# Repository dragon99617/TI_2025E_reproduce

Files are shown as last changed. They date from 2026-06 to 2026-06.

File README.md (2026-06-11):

# TI 2025E Reproduce

本项目用于复刻 2025 年全国大学生电子设计竞赛 E 题“简易自行瞄准装置”相关方案

## 项目目标

- 完成小车沿黑色方形轨迹自动循迹
- 支持设置行驶圈数 N
- 实现静态自动瞄准靶心
- 实现行驶中连续瞄准
- 支持后续扩展行驶中画圆等发挥功能
- 保持底盘控制链路由 TI MSPM0 系列 MCU 完成，便于满足题目约束

## 系统架构

```text
灰度传感器 / 编码器
        |
        v
LP-MSPM0G3507  --->  H 桥驱动  --->  底盘电机 x2
        |
      UART
        |
        v
达妙 H723  <---  maxicam 视觉模块
        |
       CAN
        |
        v
DM4310-2EC x2  --->  二维云台  --->  激光模块
```

## 硬件组成

| 模块 | 推荐器件 | 作用 |
| --- | --- | --- |
| 底盘主控 | LP-MSPM0G3507 | 循迹、编码器、底盘电机闭环 |
| 瞄准主控 | 达妙 H723 | 云台控制、视觉解析、激光控制 |
| 视觉模块 | maxicam | 靶面和激光点识别 |
| 云台电机 | 达妙 DM4310-2EC x2 | yaw/pitch 二自由度云台 |
| 底盘电机 | MG513X  x2 | 差速运动 |
| 电机驱动 | 双路 H 桥驱动 | 接收 MSPM0 的 PWM/DIR 控制 |
| 循迹传感器 | 7/8 路灰度传感器 | 黑线检测 |
| 电源 | 6S 锂电  | 分路供电 |

## 免责声明

本项目仅用于电子设计竞赛学习、资料整理和方案复刻。实际搭建和调试时，请注意锂电池、激光模块、电机和高电流供电相关安全，确保接线、固定和防护措施可靠。

请根据自身条件和比赛规则合理使用本项目内容。

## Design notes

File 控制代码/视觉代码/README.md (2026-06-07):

# Maxicam Vision for MaixCAM

This folder is a standalone MaixVision project. Open this folder or `main.py`
in MaixVision, upload it to MaixCAM, and run `main.py`.

## Defaults

- UART: `/dev/ttyS0`, `115200`
- UART pins: `A16` TX, `A17` RX
- Laser pin: `A18` as `GPIOA18`, active high
- Button pin: `A19` as `GPIOA19`, active low
- Camera resolution: tries `1920x1080`, then `1280x720`, `640x360`, `640x480`
- Camera rotation: disabled
- Algorithm: original traditional OpenCV rectangle/circle tracking

All hardware choices are in `config.py`.

## Button

- Short press: select next task
- Long press while idle: run selected task
- Long press while running: stop current task

## UART task commands

The same UART is reserved for task control input. Send ASCII text ending with
`\n` or `\r`.

- `1`: run task 1
- `2`: run task 2
- `3l`: run task 3 left
- `3r`: run task 3 right
- `4`: run task 4
- `5`: run task 5
- `6`: run task 6

Tracking output keeps the original lower-board protocol:

- angle: `dx,dy,0,0\n`
- speed search: `333,333,vx,vy\n`
- off: `666,666,0,0\n`

## Calibration

The original laser base point was `(285, 192)` at `640x360`. This project
scales it automatically for the active camera resolution. After mounting the
camera and laser, update `BASE_POINT_REF` in `config.py` if the hit point is
offset.

If MaixVision preview or OpenCV becomes too slow at `1920x1080`, move
`1280x720` to the first item in `CAMERA_RESOLUTIONS`.

## Wiring notes

MaixCAM IO is 3.3 V. Use a transistor, optocoupler, relay, or level circuit
for the laser driver and any 5 V lower board signal.

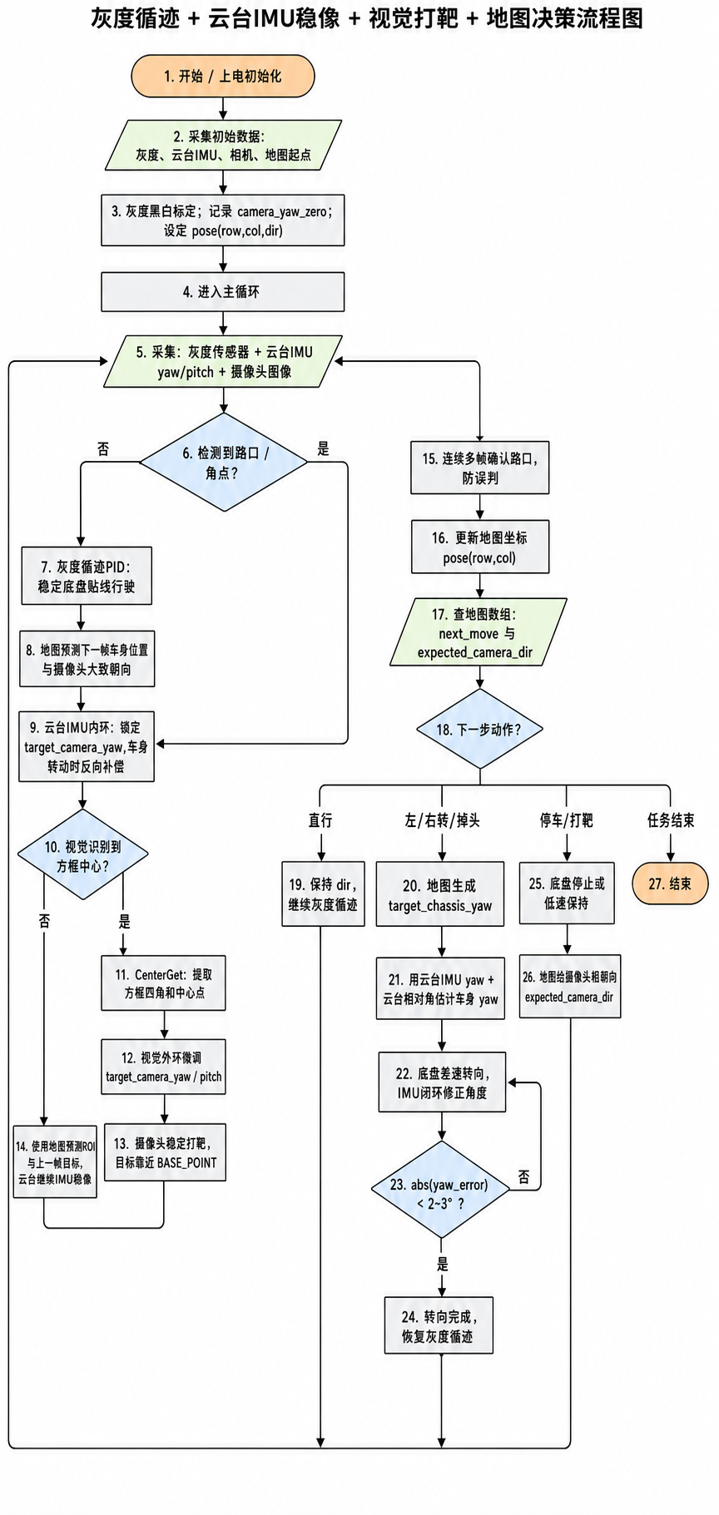
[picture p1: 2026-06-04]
控制代码/流程图.png

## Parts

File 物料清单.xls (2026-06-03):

元器件 | 预估单价 (￥)(淘宝) | 数量
达妙 4310-2EC V1.2 | 599 | 2
格氏 (Gens ace) 1300mAh 6S 75C (XT60) | 151.3 | 1
SkyRC B6AC Neo | 155 | 1
TPS5430 模块 | 20 | 1
LP-MSPM0G3507 | 160 | 1
达妙 DM-MC02 | 已买 | 1
maxicam | 已买 | 1
jlink | 已买 | 1
8路灰度传感器 | 50 | 1
MG513X电机(霍尔编码器)+加厚支架+六角联轴器+65mm四驱车轮胎 | 49.7 | 2
蓝紫色激光笔红色模组点状波长405nm带光点聚焦调节 | 25.5 | 1
CAN/UART 线材、XT30/XT60、MX1.25/GH1.25、杜邦线 | 未知 | 若干
万向轮 | 已买 | 1
SP3485en | 3.6 | 2
汇总 | 1813.1

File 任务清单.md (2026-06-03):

## 时间安排

| 时间 | 任务内容 |
| --- | --- |
| 6月8日前 | 讨论整体方案，设计小车雏形 |
| 6月8日-6月14日 | 硬件组验证各模块独立功能，完成上电测试，拼装小车，绘制并打印结构件；软件组分别阅读视觉代码和循迹代码，编写初版代码，确保基础功能正常，并确定双板互通报文格式 |
| 6月15日-6月21日 | 软件组进行联调，集中测试并解决关键问题 |

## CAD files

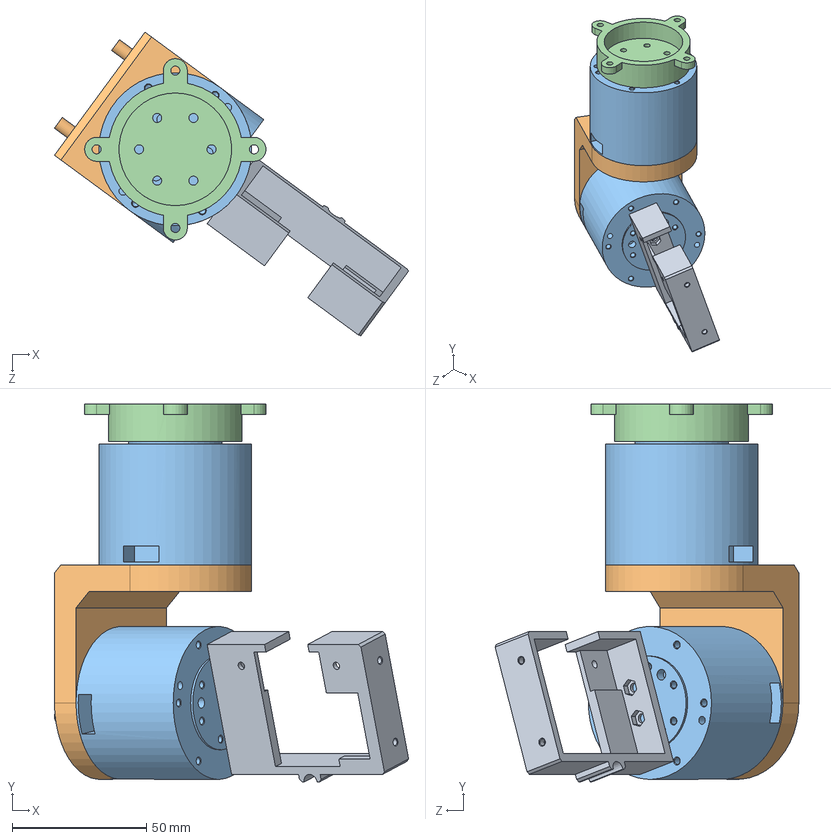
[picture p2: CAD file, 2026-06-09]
云台模型/SolidWorks/云台.SLDASM
132.1 x 141.0 x 113.3 mm
底座
J4310-无刷电机 x 2
旋转架
相机壳

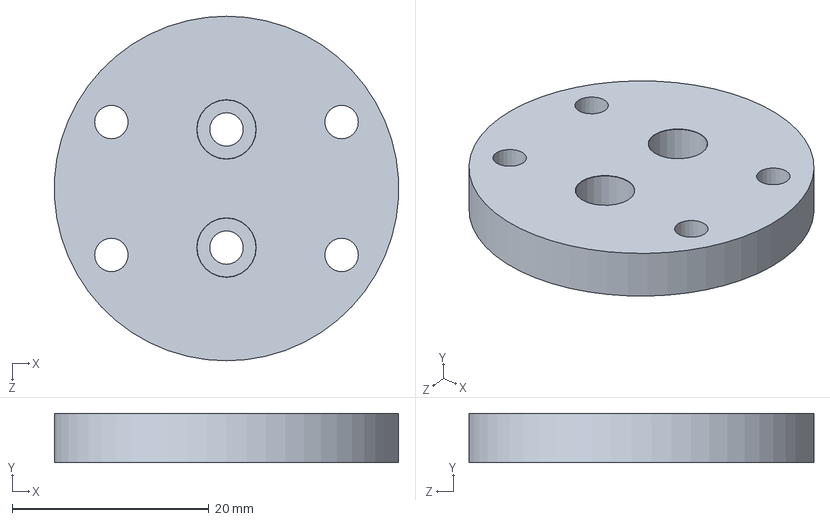
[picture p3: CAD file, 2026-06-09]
云台模型/SolidWorks/俯仰轴座.SLDPRT
34.9 x 5.00 x 35.0 mm

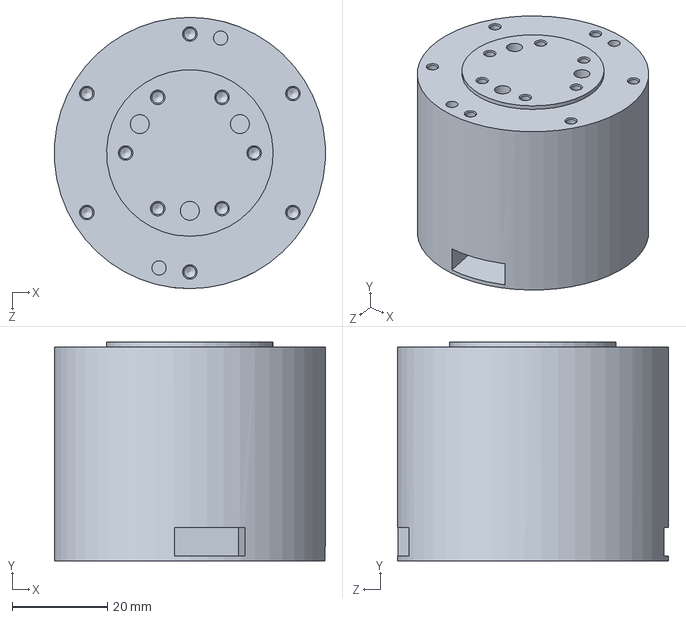
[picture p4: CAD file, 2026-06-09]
云台模型/SolidWorks/J4310-无刷电机.SLDPRT
56.9 x 46.0 x 57.0 mm

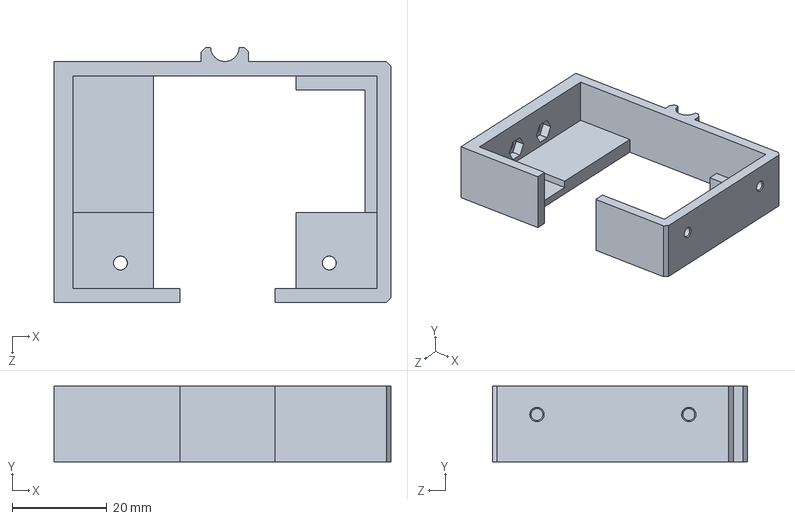
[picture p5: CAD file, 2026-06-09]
云台模型/SolidWorks/相机壳.SLDPRT
71.0 x 16.0 x 53.8 mm

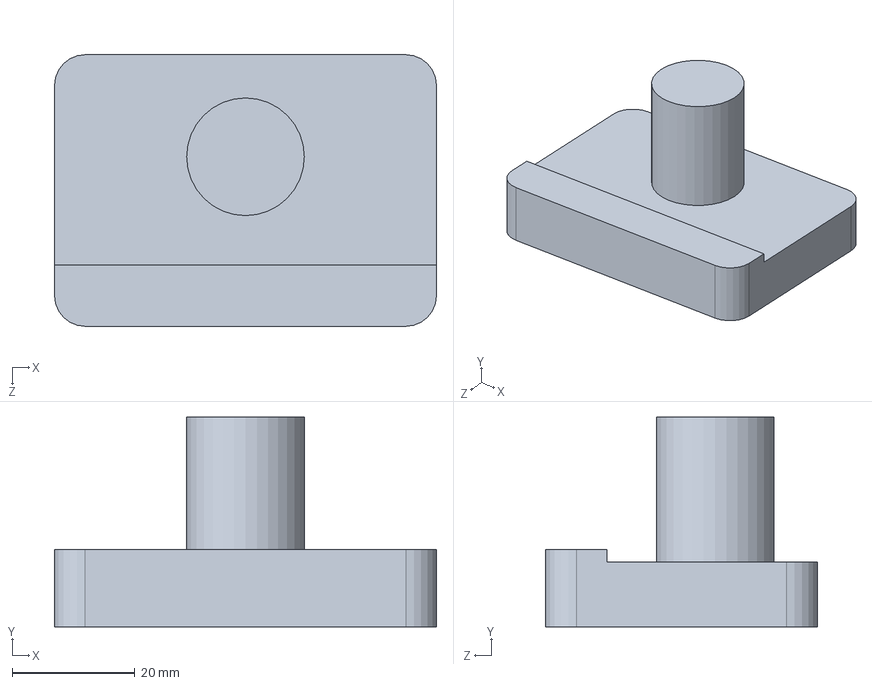
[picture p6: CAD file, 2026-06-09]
云台模型/SolidWorks/maxicam.SLDPRT
62.3 x 34.2 x 44.3 mm

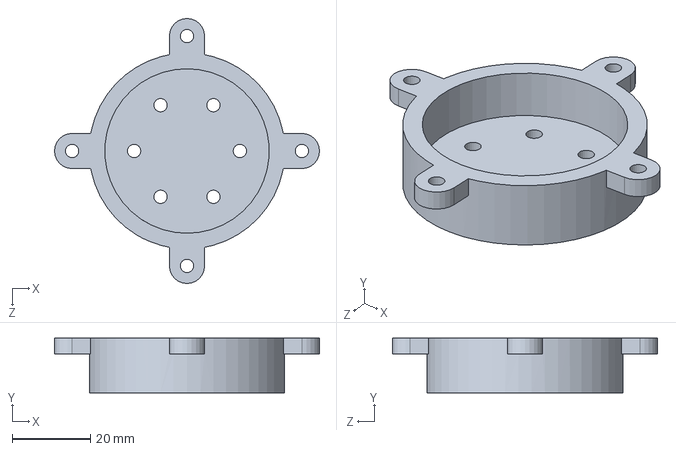
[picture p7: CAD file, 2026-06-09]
云台模型/SolidWorks/底座.SLDPRT
67.7 x 14.0 x 67.7 mm

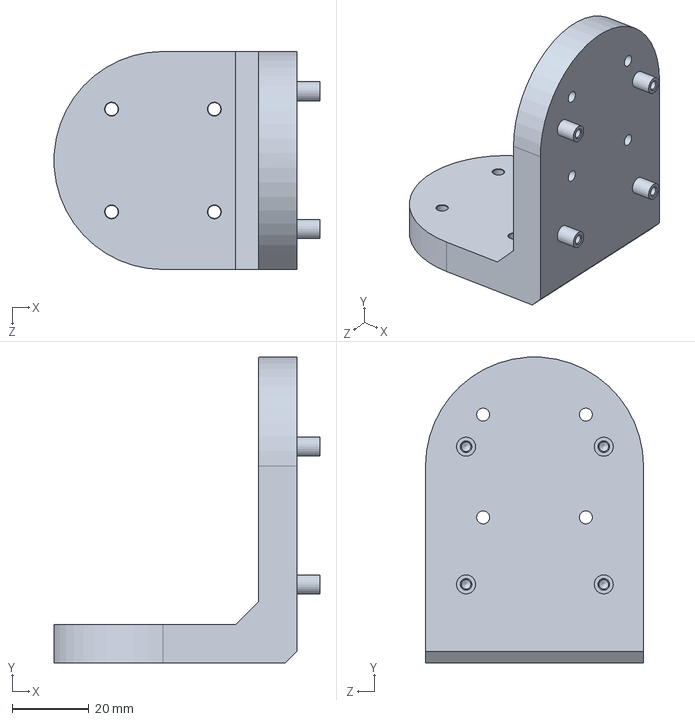
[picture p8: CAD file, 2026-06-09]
云台模型/SolidWorks/旋转架.SLDPRT
69.4 x 80.0 x 57.0 mm

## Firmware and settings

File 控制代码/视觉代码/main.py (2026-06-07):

import time

from maix import app

from config import TASK_NAMES, scaled_base_point, scaled_center_tolerance
from Drivers.Button import Button
from Drivers.CarControl import CarControl, open_serial
from Drivers.Laser import Laser
from Drivers.SerialTaskControl import SerialTaskControl
from Drivers.StatusDisplay import StatusDisplay
from Drivers.camera import Camera
from Tasks.task1 import task as task1
from Tasks.task2 import task as task2
from Tasks.task3l import task as task3l
from Tasks.task3r import task as task3r
from Tasks.task4 import task as task4
from Tasks.task5 import task as task5
from Tasks.task6 import task as task6


IDLE_PREVIEW_INTERVAL = 0.08


TASK_RUNNERS = {
    1: task1,
    2: task2,
    "3l": task3l,
    "3r": task3r,
    4: task4,
    5: task5,
    6: task6,
}
TASK_ORDER = (0, 1, 2, "3l", "3r", 4, 5, 6)


class RuntimeContext:
    def __init__(self, ui, button, serial_control, task_id, base_point, tolerance):
        self.ui = ui
        self.button = button
        self.serial_control = serial_control
        self.task_id = task_id
        self.base_point = base_point
        self.tolerance = tolerance
        self.request = None
        self._last_show = 0

    def _poll_command(self):
        button_event = self.button.poll()
        if button_event == "longPress":
            return ("stop", None)

        serial_event = self.serial_control.poll()
        if serial_event:
            return serial_event
        return None

    def should_stop(self):
        if app.need_exit():
            return True

        command = self._poll_command()
        if command is None:
            return False

        self.request = command
        return True

    def show_frame(self, maix_img, message="", center=None):
        now = time.time()
        if now - self._last_show < 0.05:
            return
        self._last_show = now
        self.ui.show_frame(maix_img, self.task_id, message, center)


def normalize_task_id(task_id):
    if task_id is None:
        return None
    if task_id in TASK_RUNNERS:
        return task_id
    return None


def apply_command(command, current_task):
    if command is None:
        return current_task, False

    action, value = command
    if action == "next":
        try:
            index = TASK_ORDER.index(current_task)
        except ValueError:
            index = 0
        return TASK_ORDER[(index + 1) % len(TASK_ORDER)], False
    if action == "select":
        task_id = normalize_task_id(value)
        return (task_id if task_id is not None else current_task), False
    if action == "run":
        task_id = normalize_task_id(value)
        if task_id is not None:
            current_task = task_id
        return current_task, True
    if action == "stop":
        return current_task, False
    return current_task, False


def run_task(task_id, camera, car, laser, ui, button, serial_control):
    runner = TASK_RUNNERS.get(task_id)
    if runner is None:
        ui.show_status(task_id, "NO TASK SELECTED")
        return None

    base_point = scaled_base_point(camera.width, camera.height)
    tolerance = scaled_center_tolerance(camera.width, camera.height)
    ctx = RuntimeContext(ui, button, serial_control, task_id, base_point, tolerance)

    ui.show_status(task_id, "RUNNING {}".format(TASK_NAMES.get(task_id, "")))
    try:
        runner(camera, car, laser, ctx)
    finally:
        laser.off()

    return ctx.request


def main():
    ui = StatusDisplay()
    ui.show_status(0, "BOOTING")

    serial_dev = open_serial()
    car = CarControl(serial_dev)
    serial_control = SerialTaskControl(serial_dev)
    laser = Laser()
    button = Button()

    camera = Camera()
    if not camera.open():
        ui.show_status(0, "CAMERA OPEN FAILED")
        while not app.need_exit():
            time.sleep(0.2)
        return

    current_task = 0
    last_preview_time = 0
    ui.show_frame(camera.read_maix(), current_task, "READY {}x{}".format(camera.width, camera.height))

    while not app.need_exit():
        command = None

        button_event = button.poll()
        if button_event == "shortPress":
            command = ("next", None)
        elif button_event == "longPress":
            command = ("run", None)

        serial_event = serial_control.poll()
        if serial_event:
            command = serial_event

        current_task, should_run = apply_command(command, current_task)
        if command:
            ui.show_frame(camera.read_maix(), current_task, "READY {}x{}".format(camera.width, camera.height))

        if should_run and current_task != 0:
            next_command = run_task(current_task, camera, car, laser, ui, button, serial_control)
            current_task, should_run_again = apply_command(next_command, current_task)
            ui.show_frame(camera.read_maix(), current_task, "READY {}x{}".format(camera.width, camera.height))
            if should_run_again and current_task != 0:
                next_command = run_task(current_task, camera, car, laser, ui, button, serial_control)
                current_task, _ = apply_command(next_command, current_task)
                ui.show_frame(camera.read_maix(), current_task, "READY {}x{}".format(camera.width, camera.height))

        now = time.time()
        if not should_run and now - last_preview_time > IDLE_PREVIEW_INTERVAL:
            last_preview_time = now
            ui.show_frame(camera.read_maix(), current_task, "READY {}x{}".format(camera.width, camera.height))

        time.sleep(0.05)

    laser.off()
    car.send_off()
    camera.close()


if __name__ == "__main__":
    main()

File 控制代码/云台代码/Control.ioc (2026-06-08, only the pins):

Mcu.UserName=STM32H723VGTx
PA11.Signal=FDCAN1_RX
PA12.Signal=FDCAN1_TX
PE7.Signal=UART7_RX
PE8.Signal=UART7_TX

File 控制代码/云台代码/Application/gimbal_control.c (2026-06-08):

#include "gimbal_control.h"

#include <stdbool.h>
#include <stdint.h>
#include <stdlib.h>
#include <string.h>

#include "dm4310_fdcan.h"
#include "fdcan.h"
#include "main.h"
#include "tim.h"
#include "usart.h"

#define YAW_MOTOR_ID                 1u
#define PITCH_MOTOR_ID               2u

#define VISION_RX_BUFFER_SIZE        64u
#define VISION_TIMEOUT_MS            500u

#define YAW_CENTER_RAD               (-0.456f)
#define PITCH_CENTER_RAD             2.31f
#define PITCH_MIN_RAD                2.15f
#define PITCH_MAX_RAD                2.35f

#define VISION_MAX_X                 320
#define VISION_MAX_Y                 240
#define VISION_OFF_CODE              666
#define VISION_NONE_CODE             404
#define VISION_SEARCH_CODE           333

#define VISION_SEARCH_SPEED_SCALE    100.0f
#define VISION_PID_OUTPUT_LIMIT_RPM  20.0f
#define MOTOR_HOME_MS                1000u
#define MOTOR_HOME_PERIOD_MS         5u

#define MIT_HOME_KP                  30.0f
#define MIT_HOME_KD                  1.0f
#define MIT_SPEED_KD                 0.8f

typedef struct {
    float kp;
    float ki;
    float kd;
    float target;
    float sum_error;
    float last_error;
    float output_min;
    float output_max;
} PID_State;

typedef struct {
    int32_t value[4];
    uint32_t tick_ms;
    bool received;
} Vision_State;

__attribute__((section(".ram_d2"), aligned(32)))
static uint8_t vision_rx_buffer[VISION_RX_BUFFER_SIZE];

static DM4310_Motor yaw_motor;
static DM4310_Motor pitch_motor;
static DM4310_Motor *motor_list[] = { &yaw_motor, &pitch_motor };

static volatile bool pitch_feedback_ready;
static volatile float yaw_speed_rpm;
static volatile float pitch_speed_rpm;
static volatile bool pitch_hold_center;
static volatile bool motor_limp;
static volatile Vision_State vision_state = {
    .value = { VISION_OFF_CODE, VISION_OFF_CODE, 0, 0 },
    .tick_ms = 0,
    .received = false,
};

static PID_State yaw_pid = {
    .kp = -0.4f,
    .ki = 0.0f,
    .kd = 0.0f,
    .target = 0.0f,
    .output_min = -VISION_PID_OUTPUT_LIMIT_RPM,
    .output_max = VISION_PID_OUTPUT_LIMIT_RPM,
};

static PID_State pitch_pid = {
    .kp = -0.4f,
    .ki = 0.0f,
    .kd = 0.0f,
    .target = 0.0f,
    .output_min = -VISION_PID_OUTPUT_LIMIT_RPM,
    .output_max = VISION_PID_OUTPUT_LIMIT_RPM,
};

static float clampf(float value, float min, float max)
{
    if (value < min) {
        return min;
    }
    if (value > max) {
        return max;
    }
    return value;
}

static float pid_calc(PID_State *pid, float input)
{
    const float error = pid->target - input;
    float output;

    pid->sum_error += error;
    output = pid->kp * error + pid->ki * pid->sum_error + pid->kd * (error - pid->last_error);
    pid->last_error = error;

    return clampf(output, pid->output_min, pid->output_max);
}

static bool is_pair(int32_t a, int32_t b, int32_t code)
{
    return a == code && b == code;
}

static void vision_set_values(const int32_t values[4])
{
    vision_state.value[0] = values[0];
    vision_state.value[1] = values[1];
    vision_state.value[2] = values[2];
    vision_state.value[3] = values[3];
    vision_state.tick_ms = HAL_GetTick();
    vision_state.received = true;
}

static void vision_parse_line(const uint8_t *data, uint16_t size)
{
    char text[VISION_RX_BUFFER_SIZE + 1u];
    char *cursor;
    int32_t values[4] = { 0, 0, 0, 0 };

    if (data == NULL || size == 0u) {
        return;
    }

    if (size > VISION_RX_BUFFER_SIZE) {
        size = VISION_RX_BUFFER_SIZE;
    }
    memcpy(text, data, size);
    text[size] = '\0';

    cursor = text;
    while (*cursor == ' ' || *cursor == '\t' || *cursor == '\r' || *cursor == '\n') {
        cursor++;
    }

    if ((*cursor < '0' || *cursor > '9') && *cursor != '-' && *cursor != '+') {
        return;
    }

    for (uint8_t i = 0; i < 4u; ++i) {
        char *end;
        long parsed = strtol(cursor, &end, 10);

        if (end == cursor) {
            return;
        }

        values[i] = (int32_t)parsed;
        cursor = end;

        while (*cursor == ' ' || *cursor == '\t') {
            cursor++;
        }
        if (*cursor == ',') {
            cursor++;
        } else {
            break;
        }
    }

    vision_set_values(values);
}

static void vision_receive_restart(void)
{
    if (HAL_UARTEx_ReceiveToIdle_DMA(&huart7, vision_rx_buffer, VISION_RX_BUFFER_SIZE) == HAL_OK) {
        __HAL_DMA_DISABLE_IT(huart7.hdmarx, DMA_IT_HT);
    }
}

static void motors_send_limp(void)
{
    (void)DM4310_SendMit(&hfdcan1, yaw_motor.id, 0.0f, 0.0f, 0.0f, 0.0f, 0.0f);
    (void)DM4310_SendMit(&hfdcan1, pitch_motor.id, 0.0f, 0.0f, 0.0f, 0.0f, 0.0f);
}

static void motors_send_home_once(void)
{
    (void)DM4310_SendMit(&hfdcan1, yaw_motor.id, YAW_CENTER_RAD, 0.0f, MIT_HOME_KP, MIT_HOME_KD, 0.0f);
    (void)DM4310_SendMit(&hfdcan1, pitch_motor.id, PITCH_CENTER_RAD, 0.0f, MIT_HOME_KP, MIT_HOME_KD, 0.0f);
}

static void motors_home_blocking(void)
{
    const uint32_t count = MOTOR_HOME_MS / MOTOR_HOME_PERIOD_MS;

    for (uint32_t i = 0; i < count; ++i) {
        motors_send_home_once();
        HAL_Delay(MOTOR_HOME_PERIOD_MS);
    }
}

static void visual_loop_100hz(void)
{
    int32_t v0;
    int32_t v1;
    int32_t v2;
    bool timeout;

    v0 = vision_state.value[0];
    v1 = vision_state.value[1];
    v2 = vision_state.value[2];
    timeout = !vision_state.received || ((HAL_GetTick() - vision_state.tick_ms) > VISION_TIMEOUT_MS);

    if (timeout || is_pair(v0, v1, VISION_OFF_CODE)) {
        yaw_speed_rpm = 0.0f;
        pitch_speed_rpm = 0.0f;
        pitch_hold_center = false;
        motor_limp = true;
        return;
    }

    if (is_pair(v0, v1, VISION_NONE_CODE)) {
        yaw_speed_rpm = 0.0f;
        pitch_speed_rpm = 0.0f;
        pitch_hold_center = false;
        motor_limp = true;
        return;
    }

    motor_limp = false;

    if (is_pair(v0, v1, VISION_SEARCH_CODE)) {
        yaw_speed_rpm = (float)v2 / VISION_SEARCH_SPEED_SCALE;
        pitch_speed_rpm = 0.0f;
        pitch_hold_center = true;
        return;
    }

    if (v0 < -VISION_MAX_X || v0 > VISION_MAX_X || v1 < -VISION_MAX_Y || v1 > VISION_MAX_Y) {
        yaw_speed_rpm = 0.0f;
        pitch_speed_rpm = 0.0f;
        pitch_hold_center = false;
        return;
    }

    yaw_speed_rpm = pid_calc(&yaw_pid, (float)v0);
    pitch_speed_rpm = pid_calc(&pitch_pid, (float)v1);
    pitch_hold_center = false;
}
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

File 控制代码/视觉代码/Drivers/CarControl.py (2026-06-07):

from maix import err, pinmap, uart

from config import UART_BAUD, UART_DEVICE, UART_RX_FUNC, UART_RX_PIN, UART_TX_FUNC, UART_TX_PIN

SERIAL_ID = UART_DEVICE


def open_serial():
    err.check_raise(
        pinmap.set_pin_function(UART_TX_PIN, UART_TX_FUNC),
        "set UART TX pin failed",
    )
    err.check_raise(
        pinmap.set_pin_function(UART_RX_PIN, UART_RX_FUNC),
        "set UART RX pin failed",
    )
    return uart.UART(UART_DEVICE, UART_BAUD)


class CarControl:
    def __init__(self, serial_dev=None):
        self.ser = serial_dev or open_serial()

    def _send(self, text):
        self.ser.write_str(text)

    def send_angle(self, int1, int2):
        self._send("{},{},{},{}\n".format(int(int1), int(int2), 0, 0))

    def send_none(self):
        self._send("{},{},{},{}\n".format(404, 404, 0, 0))

    def send_speed(self, int1, int2):
        self._send("{},{},{},{}\n".format(333, 333, int(int1), int(int2)))

    def send_off(self):
        self._send("{},{},{},{}\n".format(666, 666, 0, 0))

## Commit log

2026-06-03 Add material list
    [物料清单.xls]
2026-06-03 Add README for TI 2025E Reproduce project
    This README outlines the project aimed at reproducing a simple aiming device for the 2025 National College Student Electronic Design Competition E problem, detailing objectives, system architecture, hardware components, and disclaimers.
2026-06-09 Create 云台模型
2026-06-09 Add README for 3D printed models
